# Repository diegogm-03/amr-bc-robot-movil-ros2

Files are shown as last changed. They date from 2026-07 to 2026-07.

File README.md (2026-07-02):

# AMR-BC: Robot móvil modular de bajo coste







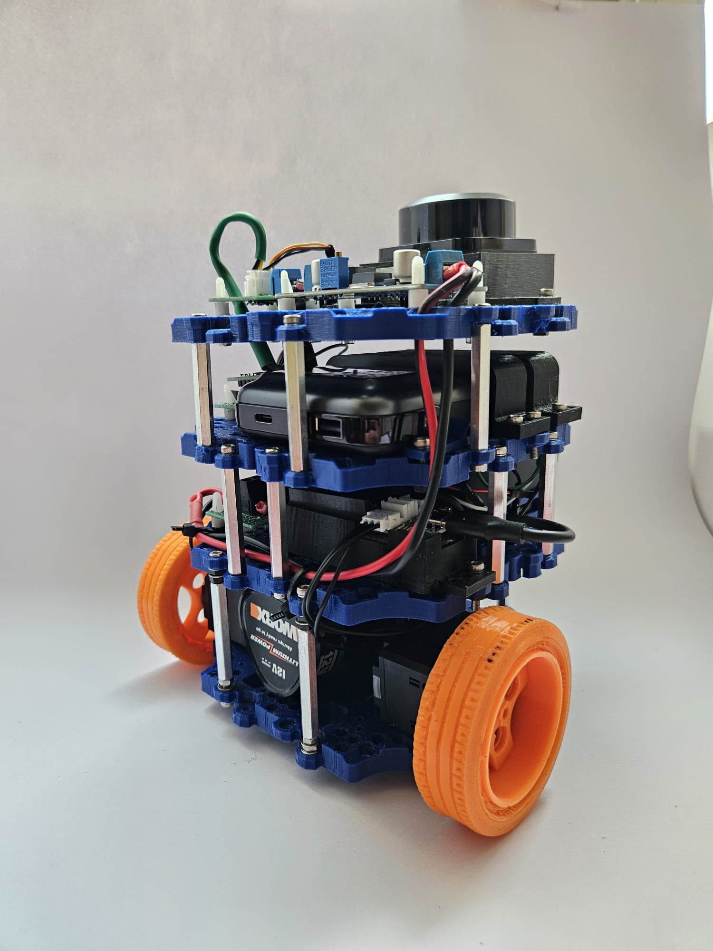
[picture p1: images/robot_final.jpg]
Robot AMR-BC


## Descripción

Este repositorio recoge el desarrollo software, el diseño mecánico y parte de la documentación técnica del robot móvil **AMR-BC**, una plataforma robótica modular de bajo coste desarrollada como Trabajo Fin de Grado en Ingeniería Electrónica Industrial y Automática.

El proyecto integra diseño mecánico mediante impresión 3D, electrónica de control, sensorización, comunicación hardware-software y validación funcional mediante ROS 2.

La plataforma está basada en una **Raspberry Pi 5**, un controlador **OpenRB-150**, motores **DYNAMIXEL XL430**, un sensor **RPLIDAR C1**, una IMU **BNO055** y una arquitectura de alimentación separada para potencia y computación.

## Características principales

- Robot móvil de bajo coste con arquitectura modular.
- Chasis y soportes diseñados mediante CAD e impresión 3D.
- Control de motores DYNAMIXEL XL430 mediante bus TTL.
- Comunicación entre Raspberry Pi 5 y OpenRB-150.
- Integración del LiDAR RPLIDAR C1 mediante UART.
- Lectura de la IMU BNO055 mediante I2C.
- Visualización de datos LiDAR en ROS 2 y RViz2.
- Pruebas de teleoperación y validación percepción-actuación.
- Separación entre alimentación de potencia y alimentación de computación.
- Archivos STL y SolidWorks incluidos para documentación y fabricación mecánica.

## Arquitectura del sistema

El robot se estructura en los siguientes subsistemas:

| Subsistema | Elementos principales |
|---|---|
| Computación | Raspberry Pi 5 |
| Control de actuadores | OpenRB-150 |
| Actuación | Motores DYNAMIXEL XL430 |
| Percepción | RPLIDAR C1 e IMU BNO055 |
| Alimentación | Batería de 12 V y power bank USB-C PD |
| Software | Debian, Docker, ROS 2 Humble, Python y RViz2 |
| Diseño mecánico | Piezas CAD, STL y SolidWorks |

## Demostraciones

A continuación se muestran algunas pruebas realizadas durante la validación del robot móvil AMR-BC.

### Teleoperación del robot

Prueba de control manual del robot mediante teclado, verificando el movimiento de los motores DYNAMIXEL y la respuesta del sistema en tiempo real.

[Ver vídeo en YouTube](https://www.youtube.com/shorts/N6F5oDQjqJE)

### Lectura de la IMU BNO055

Validación de la comunicación I2C entre la Raspberry Pi 5 y la IMU BNO055, obteniendo datos de orientación, aceleración, giroscopio y magnetómetro.

[Ver vídeo en YouTube](https://www.youtube.com/shorts/N6F5oDQjqJE?feature=share)

### Validación del LiDAR en RViz2

Prueba de adquisición de datos del sensor RPLIDAR C1 mediante ROS 2 y visualización del escaneo 2D en RViz2.

[Ver vídeo en YouTube](https://www.youtube.com/watch?v=fPHqbw8lGJI)

### Teleoperación y escaneo LiDAR en tiempo real

Prueba conjunta donde el robot se controla por teleoperación mientras el LiDAR actualiza en tiempo real la representación del entorno en RViz2.

[Ver vídeo en YouTube](https://www.youtube.com/shorts/moTShs6l5g4?feature=share)

## Estructura del repositorio

```text
.
├── docs/                          # Esquemas, imágenes y documentación auxiliar
├── src/                           # Código fuente del robot
│   ├── lidar/
│   │   └── iniciar_lidar_rviz.sh
│   ├── imu_bno055/
│   │   └── prueba_bno055_i2c.py
│   ├── teleoperacion/
│   │   ├── iniciar_teleop.sh
│   │   └── teleop.py
│   └── openrb_dynamixel/
│       └── teleop_test.ino
├── ros2/                          # Configuración ROS 2, launch y RViz
├── cad/                           # Archivos CAD y piezas imprimibles
│   ├── stl/                       # Modelos STL preparados para impresión 3D
│   └── solidworks/                # Archivos editables originales de SolidWorks
├── images/                        # Imágenes utilizadas en el README
├── videos/                        # Enlaces a vídeos de validación
├── .gitignore
├── README.md
└── LICENSE
```

## Código incluido

El repositorio incluye los principales scripts utilizados durante la validación funcional del robot móvil AMR-BC.

| Archivo | Descripción |
|---|---|
| `src/lidar/iniciar_lidar_rviz.sh` | Script de arranque del RPLIDAR C1 y RViz2 dentro del contenedor Docker. |
| `src/imu_bno055/prueba_bno055_i2c.py` | Script de prueba para validar la comunicación I2C con la IMU BNO055. |
| `src/teleoperacion/iniciar_teleop.sh` | Script de inicio de la teleoperación desde la Raspberry Pi 5. |
| `src/teleoperacion/teleop.py` | Programa principal de control por teclado, enviando comandos serie a la OpenRB-150. |
| `src/openrb_dynamixel/teleop_test.ino` | Código cargado en la OpenRB-150 para controlar los motores DYNAMIXEL XL430. |

## Diseño mecánico

El repositorio también incluye archivos CAD relacionados con el diseño mecánico del robot.

| Carpeta | Descripción |
|---|---|
| `cad/stl/` | Archivos STL preparados para laminado e impresión 3D. |
| `cad/solidworks/` | Archivos originales editables de SolidWorks. |

Las piezas mecánicas incluyen soportes, elementos estructurales, llantas, neumáticos y piezas auxiliares diseñadas para la integración física de los componentes del robot.

Los archivos `.stl` están orientados a la fabricación mediante impresión 3D, mientras que los archivos de SolidWorks permiten editar y adaptar la geometría original de las piezas.

## Ejecución básica

### Teleoperación

Para iniciar la teleoperación desde la Raspberry Pi 5:

```bash
./iniciar_teleop.sh
```

El script comprueba la conexión de la OpenRB-150 en `/dev/ttyACM0`, arranca el contenedor Docker `tfg_robot_movimiento` y ejecuta el programa `teleop.py`.

Los comandos utilizados son:

| Tecla | Acción |
|---|---|
| `W` | Avance |
| `S` | Retroceso |
| `A` | Giro a la izquierda |
| `D` | Giro a la derecha |
| `X` | Parada |

### LiDAR y RViz2

Para lanzar el sistema de percepción mediante el RPLIDAR C1 y visualizar los datos en RViz2:

```bash
./iniciar_lidar_rviz.sh
```

El script arranca el contenedor `tfg_lidar_rviz_arm64`, ejecuta el nodo `sllidar_ros2` y abre RViz2 con la configuración guardada.

Los parámetros utilizados para el LiDAR son:

| Parámetro | Valor |
|---|---|
| Puerto serie | `/dev/ttyAMA0` |
| Baudrate | `460800` |
| Frame ID | `laser` |
| Inverted | `false` |
| Angle compensate | `true` |

La comunicación del RPLIDAR C1 con la Raspberry Pi 5 se realiza mediante UART. La alimentación del LiDAR se proporciona externamente mediante un convertidor DC-DC LM2596 de 12 V a 5 V, por lo que la conexión UART se emplea únicamente para comunicación de datos.

### IMU BNO055

Para comprobar la lectura de la IMU BNO055 mediante I2C:

```bash
python3 prueba_bno055_i2c.py
```

El script muestra en tiempo real datos de temperatura, orientación Euler, aceleración, giroscopio y magnetómetro.

La conexión utilizada es:

| Señal IMU BNO055 | Raspberry Pi 5 |
|---|---|
| VIN | 3.3 V |
| GND | GND |
| SDA | GPIO2 / Pin 3 |
| SCL | GPIO3 / Pin 5 |

## Conexiones principales

### RPLIDAR C1

| Señal RPLIDAR C1 | Raspberry Pi 5 |
|---|---|
| TX | RX GPIO15 / Pin 10 |
| RX | TX GPIO14 / Pin 8 |
| GND | GND |

El RPLIDAR C1 se comunica mediante UART, empleando el puerto `/dev/ttyAMA0`.

### IMU BNO055

| Señal IMU BNO055 | Raspberry Pi 5 |
|---|---|
| VIN | 3.3 V |
| GND | GND |
| SDA | GPIO2 / Pin 3 |
| SCL | GPIO3 / Pin 5 |

La Raspberry Pi 5 actúa como maestro del bus I2C.

### OpenRB-150 y DYNAMIXEL XL430

| Elemento | Descripción |
|---|---|
| Controlador | OpenRB-150 |
| Motores | DYNAMIXEL XL430 |
| Bus | DYNAMIXEL TTL |
| Motor izquierdo | ID `1` |
| Motor derecho | ID `2` |
| Baudrate DYNAMIXEL | `57600` |
| Comunicación Raspberry Pi 5 - OpenRB-150 | USB serie `/dev/ttyACM0` |

La OpenRB-150 actúa como maestro de comunicación del bus DYNAMIXEL TTL y controla los motores conectados físicamente en cadena.

## Estado del proyecto

El sistema ha sido validado a nivel de integración hardware-software, teleoperación, lectura de IMU y visualización de datos LiDAR en RViz2.

Actualmente, el robot permite:

- Control manual mediante teleoperación.
- Comunicación entre Raspberry Pi 5 y OpenRB-150.
- Control de motores DYNAMIXEL XL430.
- Lectura de datos de la IMU BNO055 mediante I2C.
- Visualización del entorno mediante RPLIDAR C1 en RViz2.
- Separación entre alimentación de potencia y alimentación de computación.
- Consulta de archivos mecánicos para impresión 3D y edición CAD.

Como líneas futuras se plantea la integración completa de la IMU en ROS 2, la implementación de navegación autónoma, la caracterización experimental de la autonomía y la mejora de la arquitectura software mediante paquetes ROS 2 específicos.

## Autor

**Diego Luis García Montoya**  
Grado en Ingeniería Electrónica Industrial y Automática  
Universidad de Almería

## Licencia

Este proyecto se distribuye bajo licencia MIT. Consulte el archivo `LICENSE` para más información.

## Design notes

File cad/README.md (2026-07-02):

# Archivos CAD

Esta carpeta contiene los archivos relacionados con el diseño mecánico del robot móvil **AMR-BC**.

Las piezas fueron diseñadas mediante software CAD y fabricadas mediante impresión 3D, permitiendo una arquitectura modular y adaptable a los distintos componentes electrónicos del robot.

## Estructura de la carpeta

```text
cad/
├── stl/              # Archivos preparados para impresión 3D
└── solidworks/       # Archivos editables originales de SolidWorks

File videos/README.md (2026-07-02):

# Vídeos de validación

Esta carpeta contiene los enlaces a los vídeos de validación y demostración del robot móvil **AMR-BC**.

Los vídeos se encuentran alojados en YouTube para evitar subir archivos pesados directamente al repositorio.

## Demostraciones disponibles

### Teleoperación del robot

Prueba de control manual del robot mediante teclado, verificando el movimiento de los motores DYNAMIXEL y la respuesta del sistema en tiempo real.

[Ver vídeo en YouTube](https://www.youtube.com/shorts/N6F5oDQjqJE)

---

### Lectura de la IMU BNO055

Validación de la comunicación I2C entre la Raspberry Pi 5 y la IMU BNO055, obteniendo datos de orientación, aceleración, giroscopio y magnetómetro.

[Ver vídeo en YouTube](https://www.youtube.com/shorts/N6F5oDQjqJE?feature=share)

---

### Validación del LiDAR RPLIDAR C1 en RViz2

Prueba de adquisición de datos del sensor RPLIDAR C1 mediante ROS 2 y visualización del escaneo 2D en RViz2.

[Ver vídeo en YouTube](https://www.youtube.com/watch?v=fPHqbw8lGJI)

---

### Teleoperación y escaneo LiDAR en tiempo real

Prueba conjunta donde el robot se controla por teleoperación mientras el LiDAR actualiza en tiempo real la representación del entorno en RViz2.

[Ver vídeo en YouTube](https://www.youtube.com/shorts/moTShs6l5g4?feature=share)

## Resumen de validaciones

| Prueba | Elementos validados |
|---|---|
| Teleoperación | Raspberry Pi 5, OpenRB-150 y motores DYNAMIXEL |
| IMU BNO055 | Comunicación I2C y lectura de datos inerciales |
| LiDAR en RViz2 | Comunicación UART, ROS 2 y visualización de `/scan` |
| Teleoperación + LiDAR | Funcionamiento conjunto de percepción y actuación |

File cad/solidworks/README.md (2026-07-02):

# Archivos SolidWorks

Esta carpeta contiene los archivos originales de **SolidWorks** utilizados para el diseño mecánico del robot móvil **AMR-BC**.

Estos archivos corresponden a los modelos editables de las piezas diseñadas durante el desarrollo del Trabajo Fin de Grado, incluyendo soportes, elementos estructurales y componentes auxiliares integrados en la arquitectura mecánica del robot.

## Finalidad

Los archivos incluidos en esta carpeta permiten modificar, adaptar o reutilizar el diseño mecánico del robot en futuras versiones del proyecto.

A diferencia de los archivos `.stl`, que están orientados principalmente a la impresión 3D, los archivos de SolidWorks permiten editar la geometría original de las piezas.

## Contenido

Esta carpeta puede incluir archivos como:

| Formato | Descripción |
|---|---|
| `.sldprt` | Piezas individuales diseñadas en SolidWorks |
| `.sldasm` | Ensamblajes del robot o subconjuntos mecánicos |
| `.slddrw` | Planos técnicos asociados a las piezas, si están disponibles |

## Piezas diseñadas

Entre los elementos mecánicos diseñados se incluyen:

- Soportes para sensores.
- Soporte para el LiDAR RPLIDAR C1.
- Soportes para Raspberry Pi 5 y OpenRB-150.
- Soporte para el convertidor DC-DC LM2596.
- Elementos estructurales del chasis.
- Llantas y neumáticos diseñados para impresión 3D.
- Soportes auxiliares para la integración física del sistema.

## Nota

Para fabricar directamente las piezas mediante impresión 3D, se recomienda utilizar los archivos disponibles en la carpeta `cad/stl/`.

Los archivos de esta carpeta están pensados principalmente para edición, modificación y documentación del diseño mecánico original.

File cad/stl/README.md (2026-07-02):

# Archivos STL

Esta carpeta contiene los archivos STL de las piezas imprimibles del robot móvil **AMR-BC**.

Los archivos STL están preparados para su uso en software de laminado e impresión 3D, permitiendo fabricar los soportes, elementos estructurales y piezas mecánicas diseñadas para el robot.

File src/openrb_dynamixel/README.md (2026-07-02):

# OpenRB-150 y motores DYNAMIXEL

Esta carpeta contiene el código cargado en la placa **OpenRB-150** para el control de los motores **DYNAMIXEL XL430** del robot móvil **AMR-BC**.

La OpenRB-150 recibe comandos desde la Raspberry Pi 5 mediante comunicación serie USB y actúa como maestro del bus DYNAMIXEL TTL, enviando las órdenes de velocidad a los motores.

## Archivo principal

- `teleop_test.ino`: programa cargado en la OpenRB-150. Recibe comandos por puerto serie desde la Raspberry Pi 5 y controla la velocidad de los motores DYNAMIXEL.

## Funcionamiento general

El sistema funciona de la siguiente manera:

1. La Raspberry Pi 5 ejecuta el script de teleoperación `teleop.py`.
2. El usuario pulsa una tecla de movimiento.
3. La Raspberry Pi envía un carácter por USB serie a la OpenRB-150.
4. La OpenRB-150 interpreta el carácter recibido.
5. La OpenRB-150 envía la orden correspondiente a los motores DYNAMIXEL XL430 mediante el bus TTL.

## Comandos utilizados

| Comando recibido | Acción |
|---|---|
| `w` | Avance |
| `s` | Retroceso |
| `a` | Giro a la izquierda |
| `d` | Giro a la derecha |
| `x` | Parada |

## Parámetros del sistema

| Parámetro | Valor |
|---|---|
| Controlador | OpenRB-150 |
| Motores | DYNAMIXEL XL430 |
| Motor izquierdo | ID `1` |
| Motor derecho | ID `2` |
| Protocolo DYNAMIXEL | `2.0` |
| Baudrate bus DYNAMIXEL | `57600` |
| Baudrate comunicación USB | `115200` |
| Modo de operación | Velocidad |
| Puerto DYNAMIXEL | `Serial1` |
| Puerto USB serie | `Serial` |

## Lógica de movimiento

| Acción | Motor izquierdo | Motor derecho |
|---|---:|---:|
| Avance | `50` | `-50` |
| Retroceso | `-50` | `50` |
| Giro izquierda | `-50` | `-50` |
| Giro derecha | `50` | `50` |
| Parada | `0` | `0` |

La diferencia de signo entre ambos motores se debe a su disposición física en el robot, ya que se encuentran montados enfrentados dentro de la arquitectura de tracción diferencial.

## Código utilizado

El archivo `teleop_test.ino` emplea la librería `Dynamixel2Arduino` para configurar los motores en modo velocidad y enviar órdenes de movimiento en función del comando recibido por puerto serie.

## Validación

La validación consistió en comprobar que los comandos enviados desde la Raspberry Pi 5 producían la respuesta esperada en los motores DYNAMIXEL, permitiendo el avance, retroceso, giro y parada del robot mediante teleoperación.

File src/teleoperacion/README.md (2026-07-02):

# Teleoperación

Esta carpeta contiene los scripts utilizados para la teleoperación del robot móvil **AMR-BC** desde la Raspberry Pi 5.

La teleoperación permite controlar manualmente el movimiento del robot mediante teclado, enviando comandos por comunicación serie hacia la placa **OpenRB-150**, encargada de controlar los motores **DYNAMIXEL XL430**.

## Archivos principales

- `iniciar_teleop.sh`: script de inicio que comprueba la conexión de la OpenRB-150, arranca el contenedor Docker y ejecuta el programa de teleoperación.
- `teleop.py`: script principal de control por teclado. Envía comandos serie a la OpenRB-150 mediante el puerto `/dev/ttyACM0`.

## Funcionamiento general

El sistema de teleoperación se basa en el envío de caracteres desde la Raspberry Pi 5 hacia la OpenRB-150.

| Tecla | Comando enviado | Acción |
|---|---|---|
| `W` | `w` | Avance |
| `S` | `s` | Retroceso |
| `A` | `a` | Giro a la izquierda |
| `D` | `d` | Giro a la derecha |
| `X` | `x` | Parada |

## Parámetros utilizados

| Parámetro | Valor |
|---|---|
| Puerto serie | `/dev/ttyACM0` |
| Baudrate | `115200` |
| Contenedor Docker | `tfg_robot_movimiento` |
| Script ejecutado | `teleop.py` |

## Ejecución

Para iniciar la teleoperación desde la Raspberry Pi 5:

```bash
./iniciar_teleop.sh
```

En caso de que el archivo no tenga permisos de ejecución, se puede aplicar:

```bash
chmod +x iniciar_teleop.sh
```

y después ejecutarlo de nuevo:

```bash
./iniciar_teleop.sh
```

## Validación

La validación consistió en comprobar el movimiento del robot en tiempo real mediante comandos de teclado, verificando la respuesta de los motores DYNAMIXEL y la comunicación correcta entre la Raspberry Pi 5 y la OpenRB-150.

```bash
./iniciar_teleop.sh

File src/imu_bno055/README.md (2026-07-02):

# IMU BNO055

Esta carpeta contiene el script utilizado para validar la comunicación entre la **Raspberry Pi 5** y la **IMU BNO055** mediante el bus **I2C**.

La IMU permite obtener datos de orientación, aceleración, velocidad angular, campo magnético y temperatura, siendo utilizada como sensor inercial dentro de la arquitectura del robot móvil AMR-BC.

## Archivo principal

- `prueba_bno055_i2c.py`: script de prueba para comprobar la comunicación I2C con la IMU BNO055 y visualizar sus medidas en tiempo real.

## Conexión utilizada

| Señal IMU BNO055 | Raspberry Pi 5 |
|---|---|
| VIN | 3.3 V |
| GND | GND |
| SDA | GPIO2 / Pin 3 |
| SCL | GPIO3 / Pin 5 |

La Raspberry Pi 5 actúa como maestro del bus I2C, mientras que la IMU BNO055 funciona como dispositivo esclavo.

## Datos mostrados por el script

El script permite visualizar en terminal las siguientes magnitudes:

| Magnitud | Descripción |
|---|---|
| Temperatura | Temperatura interna del sensor |
| Orientación Euler | Heading, Roll y Pitch |
| Aceleración | Aceleración lineal en m/s² |
| Giroscopio | Velocidad angular en rad/s |
| Magnetómetro | Campo magnético en µT |

## Ejecución

Para ejecutar la prueba:

```bash
python3 prueba_bno055_i2c.py

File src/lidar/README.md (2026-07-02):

# LiDAR RPLIDAR C1

Esta carpeta contiene los archivos utilizados para la validación del sensor **RPLIDAR C1** mediante **ROS 2 Humble** y **RViz2**.

El LiDAR se comunica con la Raspberry Pi 5 mediante UART, mientras que su alimentación se realiza de forma externa mediante un convertidor DC-DC LM2596 de 12 V a 5 V. Por tanto, la conexión UART se emplea únicamente para la comunicación de datos.

## Archivo principal

- `iniciar_lidar_rviz.sh`: script de arranque utilizado para lanzar el nodo del RPLIDAR C1 dentro del contenedor Docker y abrir RViz2 con la configuración guardada.

## Parámetros utilizados

| Parámetro | Valor |
|---|---|
| Contenedor Docker | `tfg_lidar_rviz_arm64` |
| Puerto serie | `/dev/ttyAMA0` |
| Baudrate | `460800` |
| Frame ID | `laser` |
| Inverted | `false` |
| Angle compensate | `true` |
| Configuración RViz2 | `/root/ros2_ws/lidar_c1_config.rviz` |

## Comando ROS 2 utilizado

```bash
ros2 run sllidar_ros2 sllidar_node --ros-args \
-p serial_port:=/dev/ttyAMA0 \
-p serial_baudrate:=460800 \
-p frame_id:=laser \
-p inverted:=false \
-p angle_compensate:=true

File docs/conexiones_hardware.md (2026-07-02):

# Conexiones hardware del robot AMR-BC

Este documento resume las principales conexiones hardware utilizadas en el robot móvil AMR-BC.

## Raspberry Pi 5 - RPLIDAR C1

| Señal RPLIDAR C1 | Raspberry Pi 5 |
|---|---|
| TX | RX GPIO15 / Pin 10 |
| RX | TX GPIO14 / Pin 8 |
| GND | GND |

El RPLIDAR C1 se comunica con la Raspberry Pi 5 mediante UART, empleando el puerto `/dev/ttyAMA0` y una velocidad de comunicación de `460800 baudios`.

La alimentación del LiDAR se realiza externamente mediante un convertidor DC-DC LM2596 de 12 V a 5 V. Por tanto, la conexión UART se emplea únicamente para comunicación de datos.

## Raspberry Pi 5 - IMU BNO055

| Señal IMU BNO055 | Raspberry Pi 5 |
|---|---|
| VIN | 3.3 V |
| GND | GND |
| SDA | GPIO2 / Pin 3 |
| SCL | GPIO3 / Pin 5 |

La IMU BNO055 se comunica con la Raspberry Pi 5 mediante el bus I2C, siendo la Raspberry Pi el maestro del bus.

## Raspberry Pi 5 - OpenRB-150

| Elemento | Conexión |
|---|---|
| Raspberry Pi 5 | USB |
| OpenRB-150 | `/dev/ttyACM0` |
| Baudrate | `115200` |

La Raspberry Pi 5 envía comandos de teleoperación por USB serie hacia la OpenRB-150.

## OpenRB-150 - Motores DYNAMIXEL XL430

Los motores DYNAMIXEL XL430 comparten un bus TTL común de alimentación y datos, conectados físicamente en cadena.

| Elemento | Descripción |
|---|---|
| Motor izquierdo | ID `1` |
| Motor derecho | ID `2` |
| Protocolo | DYNAMIXEL Protocol 2.0 |
| Baudrate | `57600` |
| Modo de operación | Velocidad |

La OpenRB-150 actúa como maestro de comunicación del bus DYNAMIXEL TTL.

## Sistema de alimentación

| Subsistema | Alimentación |
|---|---|
| Raspberry Pi 5 | Power bank USB-C con Power Delivery |
| Motores DYNAMIXEL | Bus principal de 12 V |
| OpenRB-150 | Bus de 12 V compartido con los motores |
| RPLIDAR C1 | Convertidor DC-DC LM2596 de 12 V a 5 V |
| IMU BNO055 | 3.3 V desde Raspberry Pi 5 |

El sistema separa la alimentación de potencia, destinada a motores y periféricos, de la alimentación de computación, destinada exclusivamente a la Raspberry Pi 5.

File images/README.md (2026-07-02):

# Imágenes

Esta carpeta contiene imágenes utilizadas en el README principal y recursos visuales del robot móvil AMR-BC.

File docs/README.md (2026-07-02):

# Documentación

Esta carpeta contiene esquemas, capturas, imágenes técnicas y documentación auxiliar relacionada con la arquitectura del robot móvil AMR-BC.

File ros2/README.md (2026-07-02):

# ROS 2

Esta carpeta contiene los archivos relacionados con la configuración de ROS 2, RViz2, launch files y parámetros utilizados en la validación del robot móvil AMR-BC.

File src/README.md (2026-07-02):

# Código fuente

Esta carpeta contiene los scripts utilizados para el control, validación y pruebas del robot móvil AMR-BC.

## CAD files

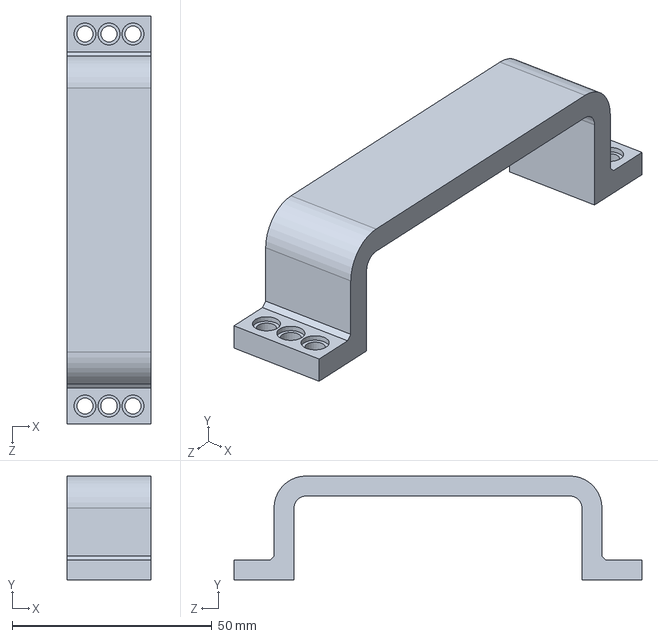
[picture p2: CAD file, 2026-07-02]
cad/solidworks/bateria.SLDPRT
21.0 x 26.0 x 102.0 mm

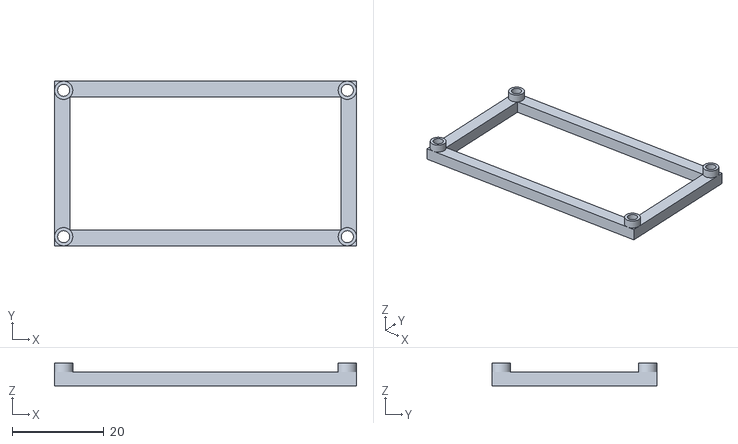
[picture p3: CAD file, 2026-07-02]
cad/stl/SOPORTE_REGULADOR.STL
66.0 x 36.0 x 5.00

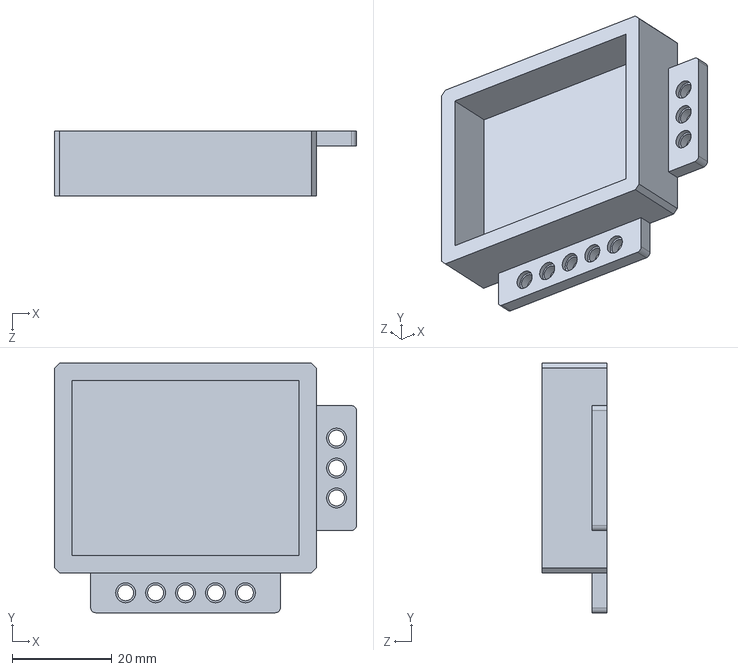
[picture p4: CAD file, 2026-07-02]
cad/solidworks/NUEVOOPENRBSOPORTE.SLDPRT
60.5 x 50.0 x 13.0 mm

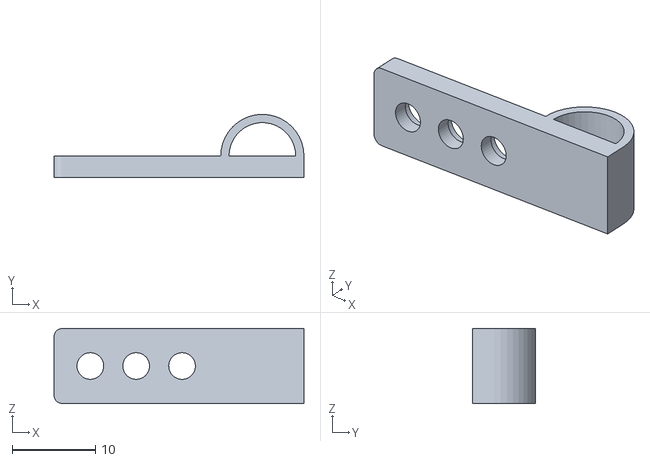
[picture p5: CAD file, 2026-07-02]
cad/stl/soportes para cables.STL
30.0 x 7.60 x 9.00

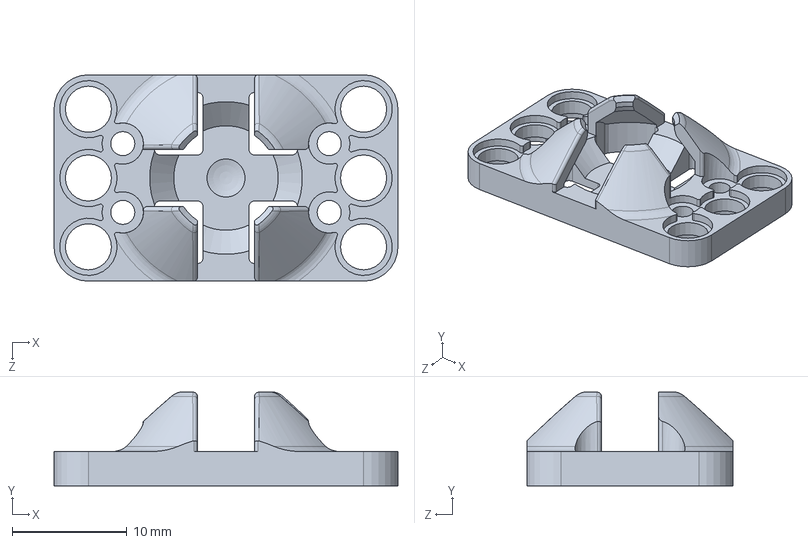
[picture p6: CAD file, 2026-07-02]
cad/solidworks/ball_caster - PR21_CASTER_CVR_3X5_REV6.SLDPRT
30.0 x 8.17 x 18.0 mm

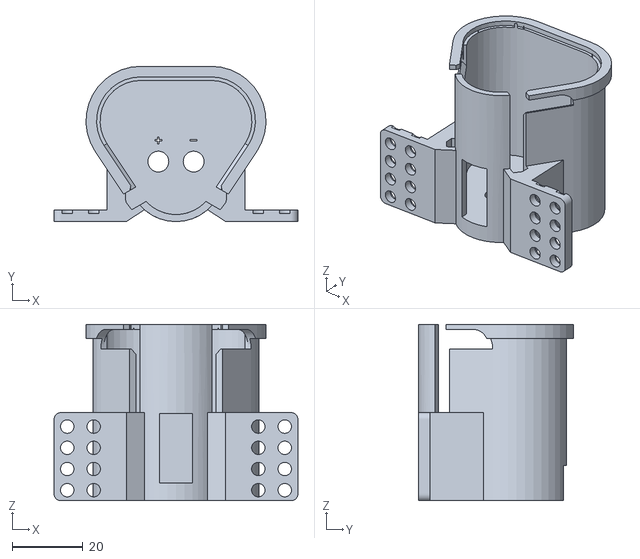
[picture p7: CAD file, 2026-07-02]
cad/stl/soporte bateria diego.STL
69.1 x 44.0 x 50.0

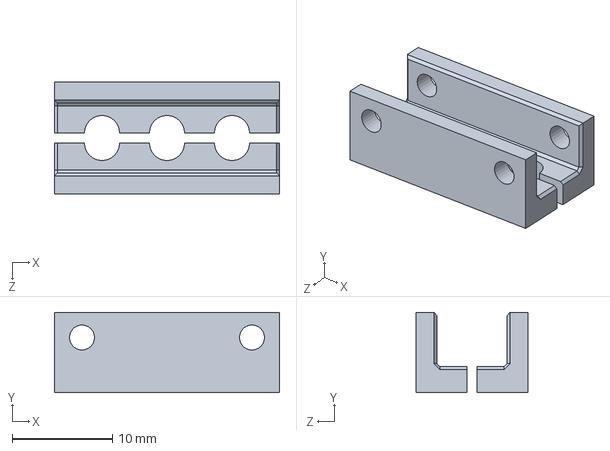
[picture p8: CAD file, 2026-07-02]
cad/solidworks/PIEZA PEDRO.SLDPRT
22.5 x 8.00 x 11.2 mm

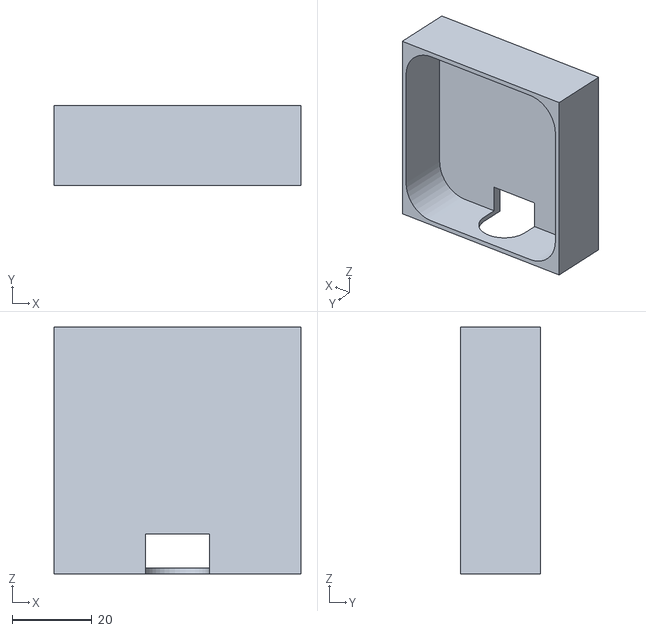
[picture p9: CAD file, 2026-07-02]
cad/stl/SOPORTE_LIDAR_C1.STL
62.0 x 20.0 x 62.0

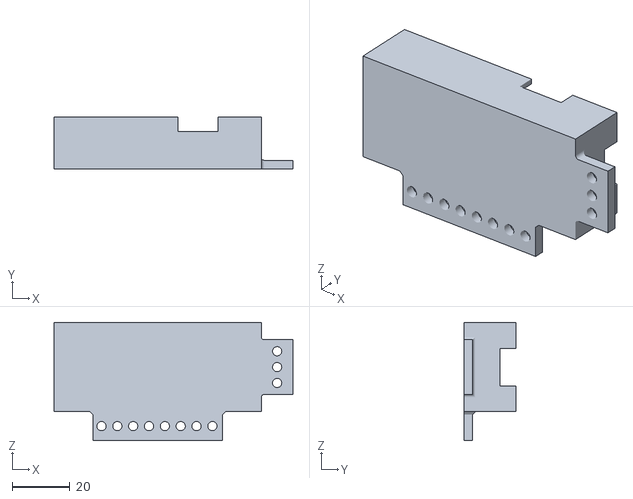
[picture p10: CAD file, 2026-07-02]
cad/stl/SOPORTEnuevo__OPEN_RB150.STL
83.0 x 18.0 x 41.0

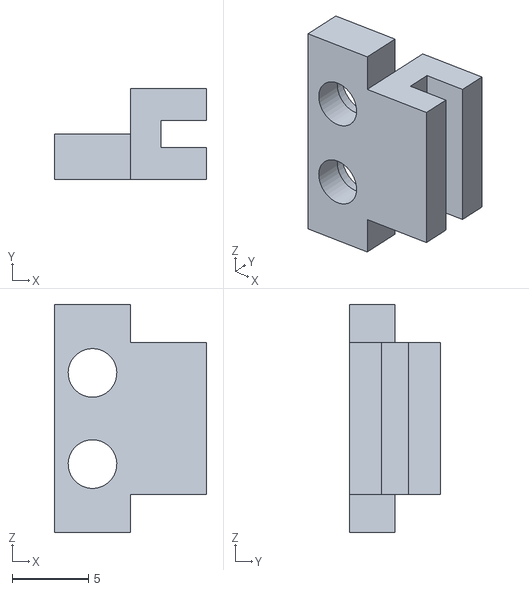
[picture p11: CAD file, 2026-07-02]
cad/stl/SOPORTE PARA PCB.STL
10.0 x 6.00 x 15.0

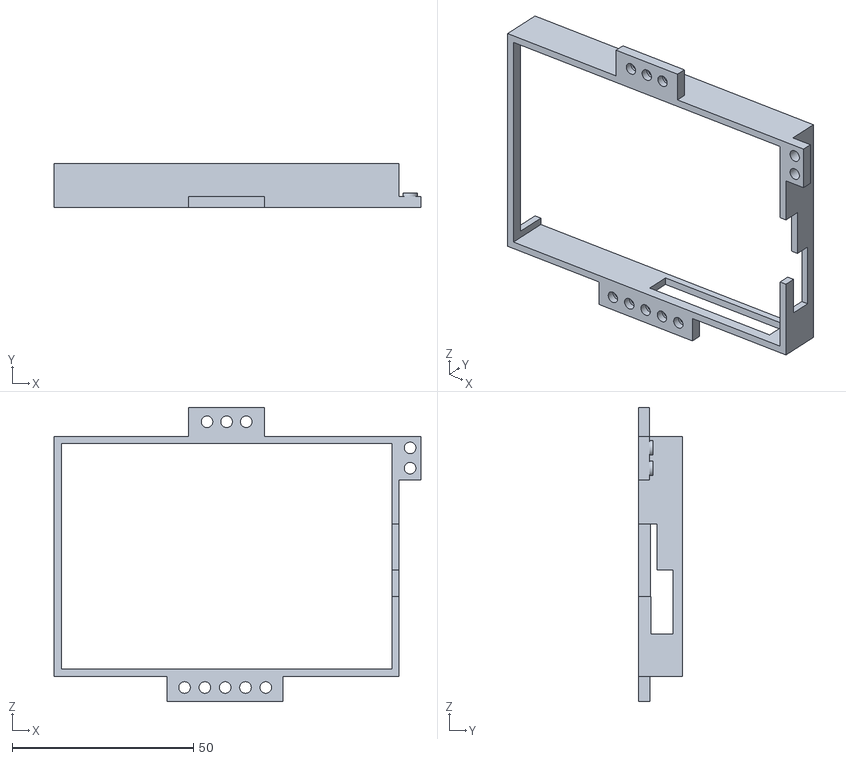
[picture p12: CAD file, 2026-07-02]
cad/stl/soportePI5.STL
101.2 x 12.0 x 81.2

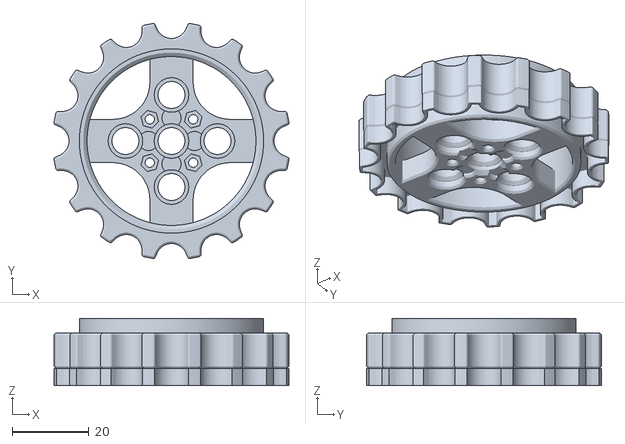
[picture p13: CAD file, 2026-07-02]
cad/stl/wheel - P30_ISP_A001_3D.stl
61.2 x 61.2 x 17.5

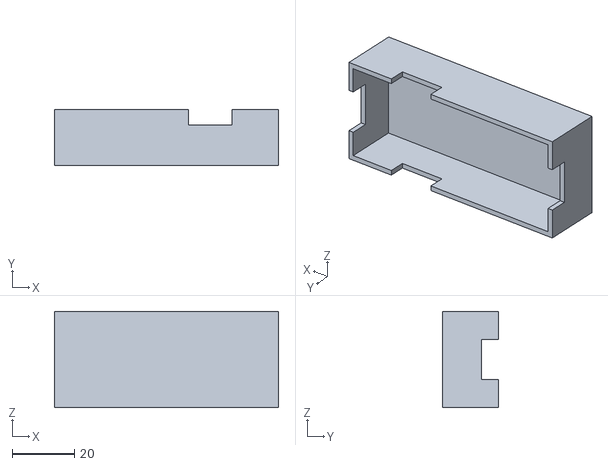
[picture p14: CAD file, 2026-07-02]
cad/stl/SOPORTE_OPEN_RB150.STL
72.0 x 18.0 x 31.0

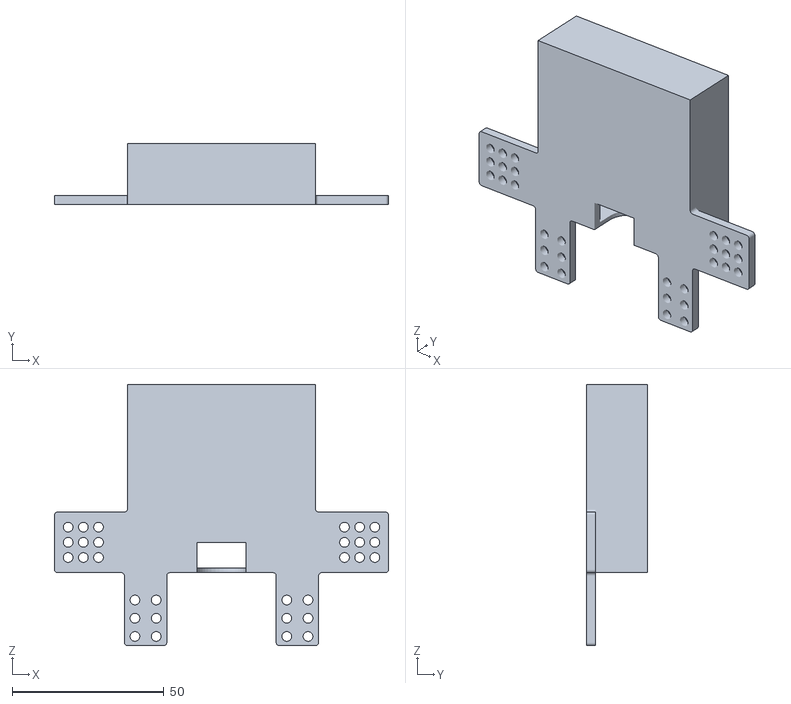
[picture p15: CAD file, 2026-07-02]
cad/stl/SOPORTE_nuevo_LIDAR_C1.STL
110.0 x 20.0 x 86.0

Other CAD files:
cad/stl/SOPORTE_INTERRUPTOR.STL
cad/stl/ball_caster - PR21_CASTER_CVR_3X5_REV6.STL
cad/stl/bateria.STL

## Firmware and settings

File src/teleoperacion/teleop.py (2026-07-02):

#!/usr/bin/env python3

"""
Teleoperación básica del robot móvil AMR-BC.

Robot móvil AMR-BC - Trabajo Fin de Grado
Autor: Diego Luis García Montoya

Este script permite controlar el robot mediante teclado desde la Raspberry Pi 5.
Los comandos se envían por comunicación serie a la OpenRB-150, que se encarga
del control de los motores DYNAMIXEL XL430.
"""

import time
import serial
import keyboard


PUERTO_SERIE = "/dev/ttyACM0"
BAUDRATE = 115200
TIEMPO_ENTRE_COMANDOS = 0.2


def main():
    puerto = serial.Serial(PUERTO_SERIE, BAUDRATE)

    print("======================================")
    print(" TELEOPERACIÓN ROBOT AMR-BC")
    print("======================================")
    print("W: adelante")
    print("S: atrás")
    print("A: izquierda")
    print("D: derecha")
    print("X: parar")
    print("Ctrl + C: salir")
    print("--------------------------------------")

    try:
        while True:
            if keyboard.is_pressed("w"):
                puerto.write(b"w")
                print("adelante")
                time.sleep(TIEMPO_ENTRE_COMANDOS)

            elif keyboard.is_pressed("s"):
                puerto.write(b"s")
                print("atrás")
                time.sleep(TIEMPO_ENTRE_COMANDOS)

            elif keyboard.is_pressed("a"):
                puerto.write(b"a")
                print("izquierda")
                time.sleep(TIEMPO_ENTRE_COMANDOS)

            elif keyboard.is_pressed("d"):
                puerto.write(b"d")
                print("derecha")
                time.sleep(TIEMPO_ENTRE_COMANDOS)

            elif keyboard.is_pressed("x"):
                puerto.write(b"x")
                print("stop")
                time.sleep(TIEMPO_ENTRE_COMANDOS)

    except KeyboardInterrupt:
        print("\nFinalizando teleoperación...")
        puerto.write(b"x")

    finally:
        puerto.close()
        print("Puerto serie cerrado.")


if __name__ == "__main__":
    main()

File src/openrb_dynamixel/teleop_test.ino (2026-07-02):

#include <Dynamixel2Arduino.h>

/*
  Control teleoperado de motores DYNAMIXEL XL430 mediante OpenRB-150.

  Robot móvil AMR-BC - Trabajo Fin de Grado
  Autor: Diego Luis García Montoya

  La Raspberry Pi 5 envía comandos por USB serie a la OpenRB-150.
  La OpenRB-150 interpreta esos comandos y controla los motores DYNAMIXEL
  conectados al bus TTL.

  Comandos:
    w -> avance
    s -> retroceso
    a -> giro izquierda
    d -> giro derecha
    x -> parada
*/

#define DXL_SERIAL   Serial1
#define DEBUG_SERIAL Serial

const int DXL_DIR_PIN = -1;

const uint8_t MOTOR_IZQ = 1;
const uint8_t MOTOR_DER = 2;

const float DXL_PROTOCOL_VERSION = 2.0;

Dynamixel2Arduino dxl(DXL_SERIAL, DXL_DIR_PIN);

using namespace ControlTableItem;

void setup() {

  DEBUG_SERIAL.begin(115200);

  dxl.begin(57600);
  dxl.setPortProtocolVersion(DXL_PROTOCOL_VERSION);

  dxl.torqueOff(MOTOR_IZQ);
  dxl.torqueOff(MOTOR_DER);

  dxl.setOperatingMode(MOTOR_IZQ, OP_VELOCITY);
  dxl.setOperatingMode(MOTOR_DER, OP_VELOCITY);

  dxl.torqueOn(MOTOR_IZQ);
  dxl.torqueOn(MOTOR_DER);

  DEBUG_SERIAL.println("CONTROL TELEOPERADO");
  DEBUG_SERIAL.println("W adelante");
  DEBUG_SERIAL.println("S atras");
  DEBUG_SERIAL.println("A izquierda");
  DEBUG_SERIAL.println("D derecha");
  DEBUG_SERIAL.println("X parar");
}

void loop() {

  if (DEBUG_SERIAL.available()) {

    char tecla = DEBUG_SERIAL.read();

    switch (tecla) {

      case 'w':
        dxl.setGoalVelocity(MOTOR_IZQ, 50);
        dxl.setGoalVelocity(MOTOR_DER, -50);
        break;

      case 's':
        dxl.setGoalVelocity(MOTOR_IZQ, -50);
        dxl.setGoalVelocity(MOTOR_DER, 50);
        break;

      case 'a':
        dxl.setGoalVelocity(MOTOR_IZQ, -50);
        dxl.setGoalVelocity(MOTOR_DER, -50);
        break;

      case 'd':
        dxl.setGoalVelocity(MOTOR_IZQ, 50);
        dxl.setGoalVelocity(MOTOR_DER, 50);
        break;

      case 'x':
        dxl.setGoalVelocity(MOTOR_IZQ, 0);
        dxl.setGoalVelocity(MOTOR_DER, 0);
        break;
    }
  }
}

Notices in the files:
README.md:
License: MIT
